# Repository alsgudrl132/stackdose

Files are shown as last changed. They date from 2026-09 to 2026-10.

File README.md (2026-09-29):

# stackdose

**버튼 한 번으로 내 보충제 조합(스택) 1회분을 컵에 담아 주는 디스펜서**

가루 4종과 알약·캡슐 4종을 넣어 두고, 웹에서 "운동 전", "운동 후" 같은 프리셋을 누르면 정해 둔 양만큼 담아 줍니다. 컵은 두 개로, 가루 컵은 가루 스테이션 저울 위에, 알약 컵은 알약 스테이션에 놓습니다. 가루는 저울로 무게를 재면서 목표량이 되면 멈추고, 알약은 원판이 돌면서 한 알씩 떨어뜨립니다.

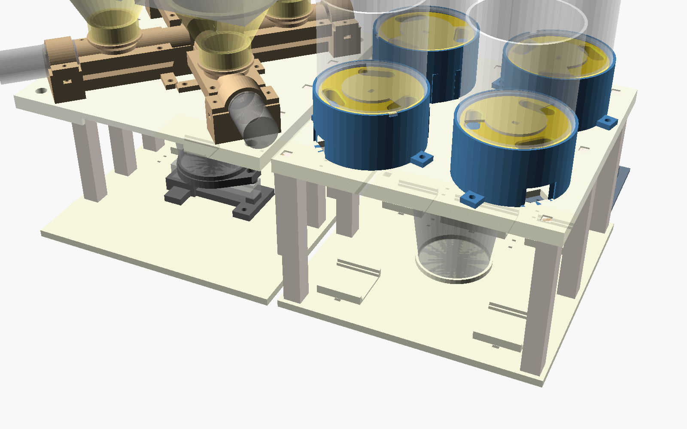
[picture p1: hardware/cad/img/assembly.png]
전체 조립


> **진행 상황 (2026-09):** 3D 설계와 배선 설계를 마쳤고, 부품을 주문하는 단계입니다. 아직 실물로 만들어 보지 않았습니다. 다음은 웹(백엔드 + 가상 디스펜서)입니다.

## 기능

- **프리셋 3개 이상:** 사용자 설정 1·2·3…마다 가루 몇 g, 알약 몇 알을 저장
- **가루 4칸:** 스크류(오거)가 가루를 밀어내고, 컵 밑 로드셀로 무게를 보면서 목표 g에서 멈춤 (폐루프)
- **알약 4칸:** 칸이 3개인 원판이 120°씩 돌아 한 알씩 배출. 자석 + 홀 센서로 원점을 찾음
- **웹 먼저:** 하드웨어가 없어도 가상 디스펜서로 전체 흐름을 돌려 볼 수 있게 만들 예정

## 구조

| 가루 모듈 | 알약 모듈 |
|---|---|
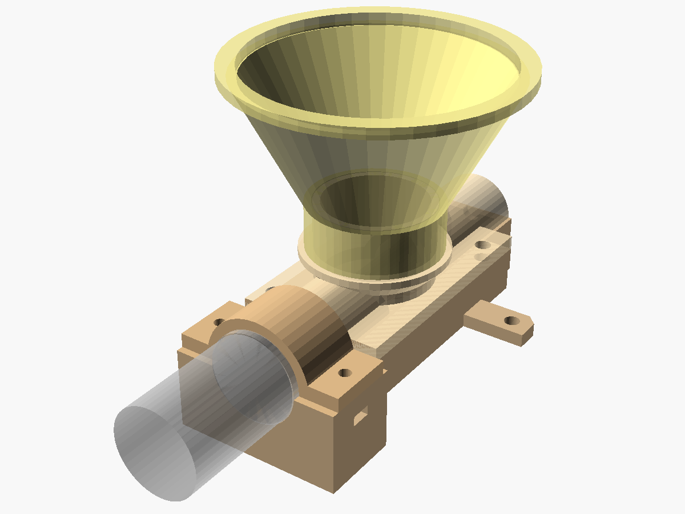
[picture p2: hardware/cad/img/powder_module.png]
가루 모듈
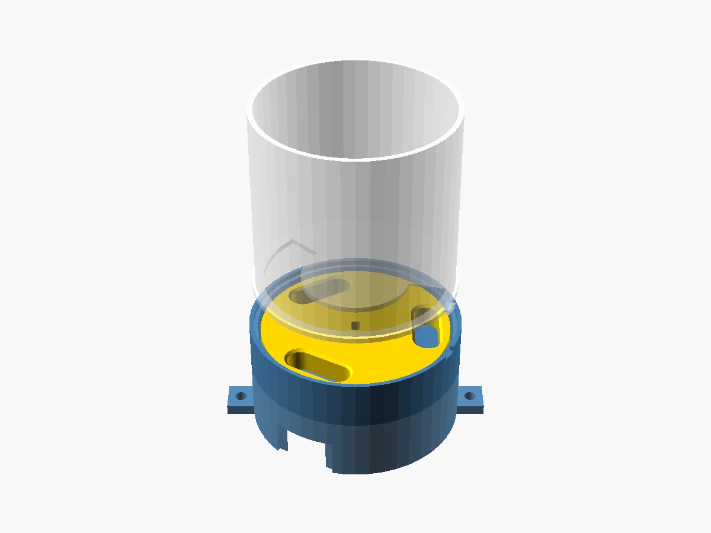
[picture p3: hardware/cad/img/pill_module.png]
알약 모듈
|  |  |
| JGA25-370 DC 모터 + 3D 프린트 스크류. 네 모듈이 컵 위에서 X자로 모임 | 28BYJ-48 스텝 모터 + 칸 3개 원판. 출구 아래 미끄럼관이 컵으로 이어짐 |

```
웹 (프리셋 선택) ──HTTP──▶ ESP32 ─┬─ DRV8833 ×2 ── 가루 모터 ×4
                                 ├─ MCP23017 (I2C) ── ULN2003 ×4 ── 알약 모터 ×4
                                 ├─ HX711 ── 로드셀 1kg (컵 무게)
                                 └─ 홀 센서 ×4 (알약 원판 원점)
```

## 폴더

| 폴더 | 내용 |
|---|---|
| [hardware/cad](hardware/cad) | OpenSCAD 설계 (치수는 `config.scad` 한 곳), 출력용 STL, 자동 검사 스크립트 |
| [hardware/wiring.md](hardware/wiring.md) | 전원, ESP32 핀 배정, 선 길이 |
| [hardware/parts.md](hardware/parts.md) | 부품표 |
| `backend/` · `frontend/` · `firmware/` | 예정 |

## 설계 원칙

- **서포트 없이 출력:** 모든 부품이 Ender-3 SE(220×220mm)에 서포트 없이 들어가도록 방향과 모양을 잡았습니다.
- **나사 20개:** 힘을 받는 곳(모터, 로드셀)에만 나사를 쓰고, 나머지는 핀·돌기·턱으로 끼우거나 한 덩어리로 출력합니다.
- **검사하고 출력:** `python hardware/cad/check.py`가 부품 렌더 오류, 출력판 크기, 떨어진 조각, 조립 상태의 부품 겹침(155쌍), 컵을 꺼내는 길, 알약 원판의 대기 위치를 검사합니다. `overhang.py`는 서포트가 필요한 면을 찾습니다.
- **공차는 쿠폰으로:** 프린터마다 다른 끼워 맞춤 여유를 공차 쿠폰 하나로 재서 `config.scad`에 넣습니다.

## 로드맵

- [x] 3D 설계 · 자동 검사
- [x] 배선 설계 · 부품 선정
- [ ] 백엔드: FastAPI + SQLite (프리셋, 배출 기록)
- [ ] 프론트엔드: 프리셋 화면 + 가상 디스펜서
- [ ] 펌웨어: ESP32 (무게 폐루프 배출, 원점 찾기)
- [ ] 출력 · 조립 · 실측값 반영

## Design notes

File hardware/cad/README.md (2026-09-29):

# stackdose · 3D 설계 (8칸: 가루 4 + 알약 4)

모든 치수는 [config.scad](config.scad) 한 곳에 있습니다. ★가 붙은 값은 **추정치**라, 부품이 도착하면 아래 측정표대로 재서 고칩니다. 숫자를 고친 뒤에는 `python check.py`로 다시 검사합니다.

OpenSCAD에서는 **파일 → 열기**로 `assembly.scad`를 여세요. 코드를 복사해서 새 창에 붙이면 `include` 파일을 못 찾습니다.

## 구조

- **가루 스테이션 (왼쪽, 210×210mm):** 스크류 4개가 컵을 중심으로 X자로 모이고, 출구 4개가 컵 입구 안으로 바로 떨어집니다. 모터는 JGA25-370이고, 반원 받침과 덮개 띠로 감싸 약 0.3mm 눌러 잡습니다. 가루통은 깔때기(호퍼) 위에 얹습니다. 컵은 로드셀 저울 위에 있어서, 무게를 보면서 스크류를 돌리고 목표량이 되면 멈춥니다.
- **알약 스테이션 (오른쪽, 205×205mm):** 원판 모듈 4개가 2×2로 놓입니다. 원판에는 칸이 3개라서 120° 돌 때마다 한 알이 나갑니다. 원판 밑의 자석과 바닥의 홀 센서로 원점을 찾습니다. 각 출구에서 비스듬한 미끄럼관을 타고 컵까지 내려갑니다.
- **제어판 (알약 스테이션 뒤):** 만능기판, ESP32, DC 잭. 배선은 [../wiring.md](../wiring.md)에 있습니다.
- 두 스테이션과 제어판은 따로 서 있고, 전선만 오갑니다. 컵은 두 스테이션 모두 **4.5mm 들어 올려 앞으로** 뺍니다.

## 파일

| 파일 | 부품 |
|---|---|
| `coupon.scad` | 공차 쿠폰 (가장 먼저 출력) |
| `powder.scad` | 가루 모듈: 아래 반쪽 관 + 모터 받침, 위 반쪽 관 + 칼라, 모터 덮개 띠, 호퍼, 스크류 |
| `pill.scad` | 알약 모듈: 치마, 바닥, 원판, 덮개 + 호퍼 (미끄럼관 모양은 여기, 출력은 알약 상판에 붙어서) |
| `scale.scad` | 저울: 로드셀 받침(과부하 멈춤대 포함), 컵 쟁반, 간격 와셔 |
| `frame.scad` | 스테이션별 바닥판(보드 받침 포함)·상판(알약 쪽은 미끄럼관 포함), 기둥, 핀 |
| `electronics.scad` | 제어판(만능기판·ESP32·DC 잭 받침 한 판), 바닥판에 붙는 보드 받침 모양 |
| `layout.scad` | 모듈 배치 계산 |
| `assembly.scad` | 전체 조립 미리보기 |
| `check.py` · `overhang.py` | 자동 검사 (아래) |

## 자동 검사가 보는 것

`python check.py` 하나로 전부 돌아갑니다.

| 검사 | 내용 |
|---|---|
| parts | 부품마다 렌더 오류 없음, 출력판(220×220×250) 안, **한 덩어리** (떨어진 조각 없음) |
| rest | 알약 원판이 멈춰 있을 때 칸이 출구 위에 걸치지 않음 |
| clash | 조립 상태에서 부품끼리 겹침 없음 (155쌍). 컵 꺼내는 길, 호퍼·가루통, 홀 센서 포함. 모터 덮개 띠의 조임만 의도한 겹침으로 허용 |
| overhang | `python overhang.py` — 서포트 없이 뽑을 수 없는 면이 있는지 |

## 출력 순서

큰 판은 작은 부품이 전부 맞는 걸 확인한 **맨 마지막**에 뽑습니다. 모듈은 **1벌 먼저** 뽑아 돌려 보고, 맞으면 나머지 3벌을 뽑습니다.

| 순서 | 부품 | 개수 | 확인할 것 |
|---|---|---|---|
| 1 | coupon | 1 | 아래 "쿠폰 읽는 법" → config 값 고치고 `check.py` |
| 2 | auger · powder_top · powder_block · powder_strap · powder_hopper | 1씩 | 스크류가 관 안에서 부드럽게 도는지, 모터가 받침에 꽉 물리는지 |
| 3 | pill_disk · pill_skirt · pill_floor · pill_cover | 1씩 | 원판이 도는지, 캡슐이 칸에 눕는지, 자석이 홀 센서 위에서 읽히는지 |
| 4 | scale_pedestal · scale_tray · scale_spacer | 1·1·2 | 로드셀 볼트가 맞는지 |
| 5 | pins | 1판 | 핀이 모듈·상판 구멍에 헐겁지 않게 들어가는지 |
| 6 | 2번 · 3번의 나머지 | 3벌씩 | |
| 7 | ctrl_plate | 1 | ESP32·만능기판이 들어가는지 |
| 8 | post | 14 | 가루 7 + 알약 7. 눕혀서 출력 |
| 9 | base_powder · deck_powder · base_pill · deck_pill | 1씩 | 가장 오래 걸림. 바닥판에 보드 받침, 알약 상판에 미끄럼관이 붙어 있음 |

출력 설정(PLA, Ender-3 SE): 레이어 0.2mm, 벽 3줄, 채움 25%, **서포트 없음**. STL은 출력 방향으로 들어 있습니다.

## 쿠폰 읽는 법

| 줄 | 표시 | 고를 칸 | 바꿀 값 |
|---|---|---|---|
| 1 | C | 8mm 핀이 **돌지만 흔들리지 않는** 칸 | `clear` = 0.1 × 칸 번호 |
| 2 | J | JGA25-370 축이 **손으로 꽉 끼는** 칸 | 스크류 허브 여유 (알려 주세요) |
| 3 | B | 28BYJ-48 축이 **손으로 꽉 끼는** 칸 | 원판 허브 여유 (알려 주세요) |
| 4 | M | M3 나사가 **힘 없이 지나가는 가장 작은** 칸 | `m3_hole` = 3.1 + 0.1 × 칸 번호 |
| 5 | H | M3 너트가 **눌러야 들어가고 안 빠지는** 칸 | `m3_nut_af` = 5.5 + 0.1 × 칸 번호 |

C 줄의 값(`clear`)이 핀·기둥 돌기·치마 턱의 헐거움을 모두 정합니다.

## 측정표 (부품 도착 후)

| 부품 | 잴 것 | config 이름 | 지금 값 |
|---|---|---|---|
| 28BYJ-48 | 몸통 지름 · 높이 | `byj_body_d` · `byj_body_h` | 28 · 19 |
| | 고정 구멍 중심 간격 · 귀 두께 | `byj_ear_span` · `byj_ear_t` | 35 · 0.8 |
| | 몸통 중심 ↔ 축 중심 거리 | `byj_shaft_off` | 8 |
| | 축 지름 · 깎인 폭 · 돌기 위 길이 · **깎인 부분 길이** | `byj_shaft_d` · `byj_shaft_flat` · `byj_shaft_len` · `byj_flat_len` | 5 · 3 · 9 · 6 |
| | 전선 길이 · 커넥터 크기 | (알려 주세요) | 25cm · 12.5×6 |
| JGA25-370 | 치수도 값을 넣어 둠. 실제와 다르면 | `jga_*` | 치수도 |
| 로드셀 | 치수도 값을 넣어 둠 | `lc_*` | 치수도 |
| 컵 (다이소) | 바닥 지름 · 입구 지름 · 높이 | `cup_*` | 55 · 75 · 75 |
| 가루통 ×4 (다이소) | 바닥 한 변 (85mm 이하) | `bin_w` (assembly) | 85 |
| | 바닥에 뚫을 구멍 | `hop_top_id` (powder) | 70 |
| 캡슐 · 알약 | 길이 · 폭 · 두께 | `pill_l` · `pill_w` · `pill_t` | 23.5 · 8.5 · 8.5 |
| ESP32 | 보드 가로 · 세로 | `esp_w` · `esp_d` | 54.4 · 27.9 |
| ULN2003 · MCP23017 · HX711 | 보드 가로 · 세로 | `uln_*` · `mcp_*` · `hx_*` | 35×33 · 55×32 · 35×21 |
| 홀 센서 (49E) | 알맹이 폭 · 높이 · 두께 | `hall_w` · `hall_l` · `hall_t` | 4.2 · 3.2 · 1.6 |
| DC 잭 | 몸통 지름 | `dcj_d` | 11 |

## 나사 개수 (20개)

나사는 **힘을 받는 곳에만** 씁니다. 나머지는 끼우거나 얹습니다.

| 어디 | 나사 | 너트 |
|---|---|---|
| 가루 모터 덮개 띠 (모터 4개 × 2) | M3x12 × 8 | 8 |
| 알약 모터 (4개 × 2) | **M3x5** × 8 | 8 |
| 로드셀 고정 끝 / 쟁반 끝 | M5x15 × 2 / M4x12 × 2 | (로드셀 나사산에 바로) |

알약 모터 나사는 반드시 **M3x5**여야 합니다. 더 길면 끝이 원판 밑에 닿습니다.

## 나사 없이 붙는 곳

| 어디 | 방법 |
|---|---|
| 기둥 ↔ 바닥판 · 상판 | 기둥 양 끝 네모 돌기를 판의 네모 구멍에 끼움. 상판은 기둥 위에 얹힘 |
| 가루 모듈 ↔ 상판 | 상판 핀 구멍에 핀 2개를 넣고 모듈을 얹음 |
| 가루 모듈 위 관 ↔ 아래 관 | 핀 2개. 위에 호퍼와 가루통이 얹혀서 눌림 |
| 알약 모듈 ↔ 상판 | 핀 2개 |
| 알약 치마 ↔ 바닥 | 치마 윗면 턱에 바닥의 홈이 끼워짐 (돌지 않게 키 1개) |
| 알약 미끄럼관 | 상판과 한 덩어리로 출력 |
| 저울 받침 ↔ 바닥판 | 핀 2개 |
| 보드 (ULN2003 ×4, MCP23017, HX711) | 바닥판에 붙은 받침에 올리고 케이블 타이 하나 |
| ESP32 · 만능기판 · DC 잭 | 제어판 받침에 올림 / 홈에 밀어 넣음 / 케이블 타이 |

핀은 `pins` 한 판에 30개(26개 + 여분 4)가 들어 있습니다.

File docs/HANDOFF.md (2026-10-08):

# stackdose 인수인계 (2026-09-22 기준)

다음 세션(사람이든 Claude든)이 이 문서 하나만 읽고 이어서 일할 수 있게 쓴 문서입니다.
**확인한 것 / 추정(★) / 모르는 것**을 구분해 두었습니다. ★가 붙은 값을 사실처럼 말하지 마세요.

---

## 0. 한 줄 요약

보충제 디스펜서입니다. 가루 4칸은 스크류와 로드셀로 g 단위까지 담고, 알약 4칸은 원판으로 한 알씩 떨어뜨립니다. 웹 프리셋으로 1회분을 담습니다. **컵은 두 개**입니다 (가루 컵은 가루 스테이션 저울 위, 알약 컵은 알약 스테이션).

- **완료:** 3D 설계, 배선 설계, 부품 선정, GitHub 첫 커밋 (`41adc28`)
- **아직 안 함:** 실물 출력과 조립, 부품 실측, 웹, 펌웨어
- **다음 할 일:** 부품이 오면 쿠폰부터 출력. 그동안은 웹 백엔드부터 시작

---

## 1. 지금 상태

| 항목 | 상태 | 비고 |
|---|---|---|
| 3D 설계 (OpenSCAD) | ✅ 완료, 자동 검사 전부 통과 | `hardware/cad/` |
| 배선표 | ✅ | `hardware/wiring.md` |
| 부품표 | ✅ | `hardware/parts.md` |
| 부품 주문 | ⏳ 장바구니 정리까지 함. **결제했는지는 모름** | 아래 7장 |
| 출력 · 조립 | ❌ | 쿠폰부터 |
| 백엔드 (FastAPI + SQLite) | ❌ | 아래 9장 |
| 프론트 (프리셋 화면 + 가상 디스펜서) | ❌ | |
| 펌웨어 (ESP32) | ❌ | |

GitHub에는 첫 커밋 뒤에 한 가지가 더 바뀌어 있고, 아직 커밋되지 않았습니다. `hardware/parts.md`에서 28BYJ 세트를 "구매 3 + 집에 1"로 고친 것입니다.

---

## 2. 폴더

```
stackdose/
├─ README.md               GitHub 첫 화면
├─ CLAUDE.md               Claude Code 세션이 자동으로 읽는 짧은 안내
├─ CLAUDE.local.md         (git 제외) 사용자와 일하는 방식
├─ docs/HANDOFF.md         이 문서
├─ hardware/
│  ├─ parts.md             부품표 (디바이스마트)
│  ├─ wiring.md            전원 · 핀 배정 · 선 길이 · 전류
│  └─ cad/
│     ├─ README.md         출력 순서 · 쿠폰 읽는 법 · 측정표 · 나사 개수
│     ├─ config.scad       ★ 모든 공통 치수 (여기만 고침)
│     ├─ lib.scad          공용 2D/3D 모양 (slot2d, sector2d, D컷 축, teardrop, 너트 주머니 …)
│     ├─ layout.scad       모듈 배치 계산 (powder_xy, pill_center, at_powder, at_pill, at_slide …)
│     ├─ powder.scad       가루 모듈
│     ├─ pill.scad         알약 모듈 (+ 미끄럼관 모양)
│     ├─ scale.scad        저울
│     ├─ frame.scad        바닥판 · 상판 · 기둥 · 핀
│     ├─ electronics.scad  제어판, 바닥판에 붙는 보드 받침
│     ├─ assembly.scad     전체 조립 + piece(name) (겹침 검사용)
│     ├─ coupon.scad       공차 쿠폰
│     ├─ check.py          자동 검사 (parts / rest / clash)
│     ├─ overhang.py       서포트 필요 면 찾기
│     ├─ img/              README용 렌더
│     └─ stl/              출력용 STL (check.py parts 가 다시 만듦)
└─ tools/devicemart/       (git 제외) 디바이스마트 조회 스크립트
```

**예전 위치:** `C:\Users\min\Desktop\dev\sb-study\dispenser\`는 이 저장소로 옮기기 전의 사본이라 이제 안 씁니다. 거기의 `cad/pill_module_v0.scad`는 초기 시안이라 버려도 됩니다.
같은 `sb-study` 안의 `backend/`·`frontend/`는 **중단된 MT5 토이 프로젝트**입니다. stackdose와 관계없고, 다시 실행하면 안 됩니다. 이유는 `CLAUDE.local.md`에 있습니다.

---

## 3. 하드웨어 전체 그림

좌표는 mm이고 X는 왼쪽→오른쪽, Y는 앞→뒤, Z는 위입니다. 원점은 두 스테이션 사이, 바닥판 윗면입니다.

| 덩어리 | 위치 | 크기 |
|---|---|---|
| 가루 스테이션 P | 컵 중심 `cupP = [-110, 0]` | 판 210×210 |
| 알약 스테이션 L | 컵 중심 `cupL = [105, 0]` | 판 205×205 |
| 제어판 | `ctrl_c = [105, 152.5]` (L 뒤, 탁자 위) | 190×90 |

공통 높이:

| 항목 | 값 |
|---|---|
| 바닥판 두께 | `base_t = 6` (z −6~0) |
| 기둥 | 14×14, z 0~120 |
| 상판 | 아랫면 `deck_z = 120`, 두께 `deck_t = 5` → 윗면 `deck_top = 125` |
| 상판 테두리 | 아래로 `rim_h = 6`, 폭 `rim_w = 3` |

두 스테이션과 제어판은 따로 서 있고 전선으로만 이어집니다. 컵은 두 스테이션 모두 **4.5mm 들어 올린 뒤 앞(−Y)으로** 빼며, 그 길은 겹침 검사(`sweepP`, `sweepL`)로 확인합니다. 가루 쪽은 앞에 기둥이 없고, 상판 앞 테두리에 컵 폭+12 홈이 있습니다.

### 3.1 가루 모듈 (`powder.scad`) × 4

- **배치:** 가루 컵 중심에서 X자로 놓입니다 (`powder_a = [45,135,225,315]`). 출구 끝면이 컵 중심에서 `powder_d = 13`에 있습니다. 로컬 +Y가 바깥쪽입니다.
- **네 모듈의 경계:** 각 모듈은 자기 90° 구역 안에만 있도록 `own_sector()`로 잘려 있고, 이웃 모듈과 1.2mm 틈이 있습니다. 원래 앞 날개 모서리가 2.8mm 겹쳐서 이렇게 고쳤습니다.
- **관과 스크류:**
  - **관 안지름 16은 고정**입니다. 스크류 지름 = `16 − 2 × auger_gap` (config, 지금 0.5 → 15.0). 틈을 바꿀 땐 **스크류만** 다시 뽑고 block·top은 그대로 씁니다.
  - 피치 40, 날개 두께 3, 1줄 나선, 코어 6. 스크류 전체 길이는 약 80입니다 (85는 관 길이).
  - 관 길이 `L = 85` (`endcap_t 3.8 + L_in 81.2`), 축 높이 `axis_h = 24` (상판 윗면 기준).
  - 출구 13×12는 컵 쪽 끝 아래에 있습니다.
- **스크류 끝 핀:** `tip_d = 5`, 막힌 구멍 깊이 `tip_hole_d = 2.5`, 구멍 앞 벽 1.3. 막힌 구멍이라 앞으로 가루가 새지 않습니다.
  - ⚠ 이 변수는 원래 이름이 `pin_*`였는데, config의 위치 맞춤 핀과 이름이 겹쳐서 `tip_*`로 바꿨습니다. 13장을 보세요.
- **부품 5개:**
  - `block`: 아래 반쪽 관 + 모터 받침
  - `top`: 위 반쪽 관 + 칼라 Ø33 + 호퍼 턱
  - `strap`: 모터 덮개 띠
  - `hopper`: 칼라에 씌우는 60° 깔때기, 윗구멍 `hop_top_id = 70★`, 테두리 Ø80
  - `auger`: 스크류
- **모터 고정 (JGA25-370):**
  - 받침 윗면을 축보다 1mm 낮췄습니다 (`split_dz = 1.0`).
  - 띠 구멍 중심을 축보다 0.4 낮췄습니다 (`squeeze = 0.4`). 그래서 M3x12 두 개로 조이면 감속기를 약 0.3mm 눌러 잡습니다.
  - 겹침 검사에서 `motor×powder` 76mm³는 이 조임이라 허용합니다 (`ALLOW` 100mm³).
- **스크류 허브:** D컷 구멍 `hub_hole = shaft_len − boss_h − powder_hub_gap + 1.5`. 모터 돌기(boss)에 닿지 않게 `auger_y_end = L − boss_h − powder_hub_gap`(0.5)로 끝냅니다. D구멍 여유는 `jga_d_clear` (★ J줄).
- **나사 없이 조립:**
  - 상판 ↔ block: 앞 날개 핀 2개 (`powder_deck_holes()`, ±25)
  - block ↔ top: 대각선 핀 2개 (`pin_at`)
  - 위에 호퍼와 가루통이 얹혀서 무게로 눌립니다.
- **상판 전선 구멍:** 모터 전선은 대각선 r=128, Ø9 구멍으로 내려갑니다 (모터 몸통 바로 아래).
- **가루통:** 다이소 용기, 바닥 한 변 85 이하 ★. 바닥에 Ø70 구멍을 뚫어 호퍼 테두리 위에 얹습니다.

### 3.2 알약 모듈 (`pill.scad`) × 4

- **배치:** 알약 컵 중심에서 2×2로 놓입니다 (`pill_s = 51`, 모듈 중심이 대각선 72.1). 로컬 +Y(출구 90°)가 컵 쪽입니다.
- **원판:** 칸 3개, 칸 중심 반지름 `pocket_r = 27`. 원판 지름 74.3, 모듈 지름 82.5.
- **알약 크기 (2026-10-04 결정): 몸체는 최대 알약, 원판은 칸에 넣을 알약**
  - 칸 하나 크기로 모든 알약을 받을 수는 없습니다. 큰 알약에 맞추면 작은 알약이 겹치거나 세워져서 두 알씩 들어갑니다.
  - **몸체**(치마·바닥 출구·낙하관·우물 깊이·덮개 창·알약 상판 미끄럼관): 최대 알약 `pill_max_*` = 26×11×11 ★ (오메가3 1000mg 연질캡슐급, 확인 안 된 추정). 한 번만 뽑습니다.
  - **원판 칸·원판 두께**: 칸에 넣을 알약 `pill_*` = 종근당 멀티비타민 실측 18.2×9.2×5.9. 칸은 길이 +1.8, 폭 +1.0, 원판 두께는 +0.8 (= 6.7).
  - **받침판** (`pill_spacer`): 얇은 알약이면 원판을 얇게 뽑고, 우물 바닥에 받침판(최대 두께 − 원판 두께, 지금 5.1)을 깔아 원판 윗면 높이를 맞춥니다. 덮개 틈 1.5는 그대로입니다. 키(180°)로 출구 구멍을 바닥과 맞춥니다. 원판 허브는 받침판 구멍을 지나 모터 축까지 내려가서 물림 길이는 그대로입니다.
  - **알약을 바꾸면** `pill_*`만 바꾸고 원판·받침판만 다시 뽑습니다. 칸마다 알약이 달라도 됩니다.
  - **한 칸에 한 알 검사:** 원판이 두꺼워 두 알이 겹쳐 들어가거나, 세운 두 알이 나란히 들어가면 렌더가 실패합니다 (`pill.scad` assert).
  - 자석 ↔ 홀 센서 거리는 받침판만큼 멀어집니다 (지금 약 7mm). 8×3 자석이면 이 거리에서도 49E 출력이 0.6V 넘게 움직여서 원점 찾기에 충분하다고 계산했습니다 (추정, 실물 확인 필요).
  - 칸 윗면을 1mm 모따기했습니다.
- **대기 위치:** 칸이 30°·150°·270°에 있고 출구는 90°입니다. 칸 끝이 출구에서 6° 이상 떨어져 있습니다 (`rest` 검사).
  - 한 알 = 120° 회전입니다.
  - 원래 칸이 4개였는데, 4개면 어떤 각도에 세워도 칸이 출구에 걸쳐서 3개로 바꿨습니다.
- **덮개 창:** 출구 ±75°는 닫혀 있고, 나머지 구간으로 호퍼 속 알약이 칸에 들어갑니다. 창이 끝나는 쪽 모서리는 아래를 45°로 깎아서, 반쯤 걸친 알약을 끼우지 않고 밀어 넣습니다.
- **틈:** 원판 아래 0.5, 위 1.5.
- **축 구멍:** 28BYJ 축은 끝의 6mm★(`byj_flat_len`)만 D컷이라, 원판 구멍도 아래는 둥글게, 위쪽만 D자로 만들었습니다.
- **부품과 출력 방향:**
  - `skirt`: 모터가 들어가는 치마 + 낙하관 + 상판 핀 날개 2개 (30°, 210°) + 윗면 턱
  - `floor`: 바닥 + 원판 우물 + 덮개 턱
  - `disk`: 원판. 뒤집어서 출력
  - `cover`: 덮개 + 호퍼 70mm★
- **치마 ↔ 바닥:** 나사 없이 치마 윗면 안쪽 턱(1.2×2)에 바닥 아랫면 홈이 끼워집니다. 150°에 돌림 방지 키가 있습니다.
- **모터 (28BYJ-48):**
  - 귀 두 개를 아래에서 M3x5로 바닥에 조입니다.
  - 너트는 바닥 윗면(우물 쪽) 주머니에 들어가고, 주머니는 0.8 더 깊게 팠습니다.
  - ⚠ **M3x5보다 긴 나사를 쓰면 끝이 원판 밑에 닿습니다.**
- **원점 (홀 센서):**
  - 원판 아랫면 칸 사이에 자석 8×3 (r27.5, 대기 상태에서 350°)
  - 바로 아래 바닥 밑에 홈을 파서 바닥을 1.2mm만 남기고, 49E 센서 알맹이를 넣습니다.
  - 센서 다리와 단선은 바깥쪽 홈(7×1.8)을 따라 치마 벽으로 갑니다.
  - 자석과 센서 사이는 약 1.7mm입니다.
  - 센서는 KY-035 보드에서 떼어 다리에 단선을 납땜하고 수축튜브를 씌웁니다.
  - 센서를 홈에 고정하는 방법은 정하지 않았습니다. 테이프나 글루건 정도면 됩니다 ★.
- **전선 창:** 치마 −Y쪽에 24×14. 상판 전선 구멍(20×12)은 모듈 로컬 (0, −30)에 있습니다. 28BYJ 커넥터(약 12.5×6★)가 꽂힌 채로 통과합니다.
- **미끄럼관:** 출구에서 컵까지 이어지고, **알약 상판과 한 덩어리**로 출력합니다 (`pill_slide_solid/hole`).
  - 위: r = 45.1, z = 120
  - 아래: r = 22, z = 87 (컵을 들어 빼도 닿지 않는 높이)

### 3.3 저울 (`scale.scad`)

- **로드셀:** 1kg 바 타입 (80×12.7×12.7, 치수도). X 방향으로 가루 컵 아래에 눕힙니다.
- **고정 끝 (전선 나오는 쪽):** M5x15 두 개를 받침 아래에서 올려 끼웁니다. 머리는 5.2 파묻히고, 나사가 로드셀에 8.2mm 물립니다.
- **쟁반 끝:** M4x12 두 개를 쟁반 위에서 내려 끼우고, 사이에 간격 와셔 3mm를 넣습니다. 쟁반 두께는 7, 머리는 4.2 파묻히고, 6.2mm 물립니다.
- **assert:** 물림 길이가 5 이상이고 로드셀 두께보다 짧은지 파일 안에서 확인합니다.
- **받침:** 멈춤대까지 한 덩어리 띠(두께 6)입니다. 로드셀 끝 아래에 1.0mm 틈을 둔 과부하 멈춤대가 있습니다. 바닥판에는 핀 2개로 놓습니다.
- **컵 높이:** 컵 바닥은 z 34.7, 컵 윗면은 109.7 ★(컵 높이 75 기준).

### 3.4 뼈대 (`frame.scad`)

- **기둥:**
  - P 7개 `postsP` (컵 기준 ±93, 앞쪽 없음), L 7개 `postsL` (±92)
  - 양 끝에 6×6×4 네모 돌기가 있고, 판의 네모 관통 구멍에 끼웁니다.
  - 돌기는 기둥 한쪽 면에 붙어 있습니다 (`peg_off = -4`). 눕혀서 출력할 때 바닥에 닿게 하려는 것입니다.
  - L 기둥은 원래 ±93~95였는데 상판 테두리를 파고들어서 ±92로 옮겼습니다.
- **상판:** 뒤집어서 출력합니다. 모듈 핀 구멍은 윗면에서 3mm 막힌 구멍입니다.
- **바닥판:** 보드 받침이 붙어 있고, 케이블 타이 구멍과 바닥판 아랫면 타이 홈이 있습니다. 알약 바닥판에는 알약 컵 받침 링(높이 4)이 있습니다.
- **핀:** `pins` 한 판에 30개 (필요 26 + 여분 4). Ø4×6.5, 구멍은 `pin_hole = 4 + 2*clear`.

### 3.5 전자부품 받침 (`electronics.scad`)

- **제어판 (190×90×3, 한 판으로 출력):**
  - 만능기판 89×52 홈 받침: −X에서 밀어 넣고 +X 끝에서 멈춥니다. 긴 변 2mm 턱이 기판 윗면을 덮으니, 그 2mm 안에는 부품을 두면 안 됩니다.
  - ESP32 받침: 세로로 놓고 짧은 두 끝만 받칩니다 (높이 30). USB는 뒤쪽(+Y)입니다. **점퍼를 먼저 다 꽂고 올려놓는 방식**입니다.
  - DC 잭 받침: 케이블 타이로 고정합니다.
- **바닥판에 붙은 보드 받침** (가장자리 턱 1.5, 보드 아랫면 높이 4, 짧은 두 변은 열림, 케이블 타이 하나):
  - ULN2003 ×4: 알약 컵 기준 (±62, ±62). 각 알약 모듈 전선 구멍 바로 아래입니다.
  - MCP23017: (0, 62)
  - HX711: 가루 컵 기준 (−55, 55)

---

## 4. 전자 · 배선 요약 (자세한 건 `hardware/wiring.md`)

- **전원:** 5V 4A 어댑터 하나. 코드에서 **한 번에 모터 하나만** 돌립니다 (최악 약 1.9A).
- **ESP32 핀:**

| 용도 | 핀 |
|---|---|
| I2C (MCP23017) | 21 SDA / 22 SCL |
| HX711 | 18 DT / 33 SCK |
| DRV8833 #1 | 25, 26 (가루1) · 27, 13 (가루2) |
| DRV8833 #2 | 32, 23 (가루3) · 4, 19 (가루4) |
| nFAULT (두 드라이버 묶음) | 5 (10kΩ 풀업. 부팅 때 HIGH여야 하는 핀이라 풀업과 맞음) |
| 홀 센서 1~4 (아날로그, ADC1이라 와이파이를 켜도 읽힘) | 36, 39, 34, 35 |

- **쓰지 않은 핀:** 0, 2, 12, 15 (부팅), 6~11 (메모리 칩), 1, 3 (USB), 16, 17 (WROVER 모듈이면 못 씀).
- **MCP23017:** 주소 0x20. GPA0~3 → ULN #1, GPA4~7 → #2, GPB0~3 → #3, GPB4~7 → #4. RESET은 3V3에 이어야 합니다 (보드에 이미 연결돼 있는지는 ★).
- **DRV8833 (VLT-MD012):** EEP(nSLEEP)를 **3V3에 꼭 이어야** 모터가 돕니다. 모터 전원(VM)은 5V입니다. 모터 하나에 두 핀을 쓰고 둘 다 PWM이 됩니다.
- **부품 추가:**
  - 1000µF를 DRV마다 1개, DC 잭 옆에 1개
  - 0.1µF를 가루 모터 단자마다 1개
  - I2C 풀업 4.7kΩ ×2
- **선:**
  - 단선 0.6: 1개를 사면 빨강·검정·흰색이 1m씩 옵니다. 필요량은 빨강·검정 약 4.9m, 흰색 약 3.2m이라 6개를 삽니다.
  - F-F 30cm: ESP32, MCP, ULN에 씁니다.
  - 구간별 길이는 wiring.md에 20% 여유를 넣어 적었습니다.
- **홀 센서를 바꾼 이유:** 처음 고른 A3144E 모듈(VLT-ML005)은 칩 정격이 4.5V 이상이라 3.3V에서는 규격 밖입니다. 5V로 주면 출력도 5V라 ESP32 입력을 망가뜨릴 수 있습니다. 그래서 KY-035(49E 아날로그, 3.3~5V)로 바꿨습니다.

---

## 5. 자동 검사 (`hardware/cad/check.py`)

```
cd hardware/cad
python check.py            # parts + rest + clash 전부 (약 10분)
python check.py parts      # 렌더 오류 · 출력판 크기 · 한 덩어리 여부 → stl/ 다시 만듦
python check.py rest       # 알약 대기 위치에서 칸 ↔ 출구 겹침
python check.py clash powder0 deckL   # 이름이 들어간 쌍만
python overhang.py         # 서포트 필요 면 (44°)
```

- **환경:**
  - OpenSCAD 2021.01 경로: `C:\Program Files\OpenSCAD\openscad.exe`
  - Windows 콘솔에서 한글이 깨지면 `PYTHONIOENCODING=utf-8`을 붙입니다.
- **판정 방식:**
  - clash는 `assembly.scad`의 `piece(name)` 두 개를 교집합해 부피 1mm³ 이상이면 실패입니다. 15개씩 동시에 돌립니다.
  - "한 덩어리"는 OpenSCAD 로그의 `Volumes: 2`(바깥 + 덩어리 1개)로 판정합니다. `coupon`과 `pins`는 원래 여러 조각이라 뺍니다.
  - 경고(떨어진 덩어리 등)가 나와도 실패로 봅니다.
- **마지막 결과:** 아래 "검수 반영" 참고
- **overhang.py의 허점:** 폭 8mm 미만이면 모두 "다리(양쪽이 받쳐진 천장)"로 봅니다. 한쪽만 붙은 "처마"도 놓칩니다. 실제로 놓친 곳: 저울 받침 M5 머리 자리 천장(깊이를 5.8로 늘려 대응), 제어판 기판 홈 위 2mm 턱(줄칼로 다듬기).
- **check.py가 서로 검사하지 않는 쌍:** 한 덩어리로 묶인 block·top·strap, 치마·바닥, 받침·쟁반·와셔. 2026-09-28 검수에서 13쌍을 따로 돌려 모두 비어 있었습니다.
- **검사가 못 보는 것:**
  - 전선 자체의 부피
  - 나사 머리·너트 모형 (나사가 20개로 줄어서 해당하는 곳이 적음)
  - 가루 흐름, 알약 걸림, 홀 센서 신호 세기
  - 휨 (상판이 가루통 무게로 휘는지)
  - 프린터 공차

### 5.1 검수 반영 (2026-09-28)

다른 세션이 설계 전체를 검수했고(설계 오류는 없음), 아래를 반영했습니다.
- 스크류 끝 핀 구멍 앞 벽 0.5 → 1.3 (`endcap_t 3.8`, `L_in 81.2`, L은 85 그대로)
- 저울 받침 M5 머리 자리 깊이 5.2 → 5.8 (천장 처짐 대비. 물림 8.8, 로드셀 두께 12.7 미만)
- 알약 파일 `rim_h/rim_w` → `pill_rim_*` (config의 상판 테두리 값을 소리 없이 덮어쓰고 있었음)
- D구멍 여유를 `byj_d_clear`, `jga_d_clear`로 분리 (전엔 `clear/2`로 우연히 맞음)
- 숫자로 적힌 곳을 변수로: `powder_shoulder_t`(호퍼 턱 2, 4곳), `powder_hub_gap`(0.5), `powder_bolt_len`(12), `powder_nut_drop`(8), `pill_mag_fit`(자석 자리 0.3)
- `check.py`: 허용 겹침 250 → 100, 경고도 실패로 처리

**남은 검수 항목 (실물이 와야 함):**
- (반영됨 2026-10-04) 알약 크기: 몸체는 최대 알약(26×11×11 ★), 원판·받침판은 칸에 넣을 알약 (3.2절 참고). 실제 오메가3를 재면 `pill_max_*`만 확인
- 원판이 축에 마찰로만 붙음: 28BYJ 돌기 높이를 재서 `hub_down` 조정 (허브가 원판보다 먼저 돌기에 얹히게)
- 자석 자리 8.3이 빡빡할 수 있음: 자석이 오면 쿠폰 C줄 1번(8.2)·2번(8.4)에 넣어 보고 `pill_mag_fit` 조정
- 알약 덮개 가운데 Ø40이 평평해서 캡슐이 머물 수 있음: 알약 부품 뽑기 전에 가운데 원뿔 추가
- 로드셀 멈춤대 틈 1.0: 조립 후 1kg 올려 휘는 양 재고, 테이프로 맞춤
- 제어판 기판 턱: 뽑은 뒤 줄칼로 다듬기
- (확인됨 2026-10-04) 기둥 돌기 ↔ 판 구멍: `pegtest.stl`(판과 같은 `peg_holes()`)에 뽑은 기둥을 끼워 보니 잘 들어감 → 기둥 나머지 13개 진행

---

## 6. 출력 · 조립 순서

출력 설정은 PLA, 레이어 0.2, 벽 3줄, 채움 25%, **서포트 없음**입니다. STL은 출력 방향으로 들어 있습니다.
- 사용자 슬라이서 프리셋은 서포트 켜짐·벽 2줄이라 **서포트를 끄고 벽 3줄로** 바꿔야 합니다. `xy_hole/contour/elephant_foot` 보정은 0으로 두세요 (쿠폰 값이 무의미해짐).
- **스크류:** 챙(brim) 5mm, 최소 레이어 시간 10초(또는 2개를 같이), 팬 100%. 비틀림은 층 사이가 받으니 코어 Ø6과 허브 계단이 가장 약합니다.
- **큰 판(210):** 챙을 끄세요. 210 + 8×2 = 226이라 220 판을 넘습니다.
- 쿠폰과 실제 부품은 **같은 필라멘트 프리셋**으로 뽑습니다.

1. **coupon:** 결과를 config에 넣고 `check.py`를 다시 돌립니다.
   - 확정: C줄 3번 → `clear = 0.3`, B줄 4번 → `byj_d_clear = 0.15`
   - 미확인: M·H줄(M3 나사·너트 필요), J줄(JGA 모터 필요)
   - G줄(스크류 틈)은 **선택 사항**입니다. 기본값 `auger_gap = 0.5`를 유지합니다 (2026-09-30 결정).
     - 사용자 프린터는 보급형이라, 고리는 설계 16.0 → 실측 약 15.4로 작게 나오고 스크류는 그 안에서 헐렁하게 돕니다. 헐렁한 건 정상이고, 빡빡한 것(가루가 끼어 멈춤)이 더 나쁩니다.
     - 멈춘 뒤 새는 가루는 저울 폐루프(목표 근처 감속, 일찍 멈춤)와 역회전으로 잡습니다.
     - 실제 가루로 돌려서 새는 양이 문제일 때만: 먼저 출구 고무 조각·역회전 늘리기 → 그래도 안 되면 `auger_gap`을 줄이고 스크류만 재출력 (0.3 밑으로는 안 내림).
2. **가루 모듈 1벌** (auger, top, block, strap, hopper): 스크류가 부드럽게 도는지, 모터가 꽉 물리는지 봅니다.
   - **스크류는 1개만 먼저** 뽑아 실제 관과 모터로 확인한 뒤 나머지 3개를 뽑습니다.
3. **알약 모듈 1벌** (disk, skirt, floor, cover): 원판이 도는지, 캡슐이 칸에 눕는지, 자석이 읽히는지 봅니다.
4. **저울** (pedestal, tray, spacer ×2)
5. **pins**
6. **2·3번의 나머지 3벌씩**
7. **ctrl_plate**
8. **post ×14:** 눕혀서 출력합니다.
9. **큰 판 4장** (base_powder, deck_powder, base_pill, deck_pill): 가장 오래 걸립니다.

**조립할 때 주의:**
- **스크류는 먼저 모터 축에 끼우고, 모터와 함께 받침에 내려놓습니다.** 끝 핀 구멍 앞뒤 여유가 0.5뿐이고 축이 허브에 8.5mm 들어가서, 모터를 먼저 놓으면 스크류를 끼울 수 없습니다.
- ESP32는 점퍼를 먼저 꽂고 받침에 올립니다.
- 알약 모터는 바닥에 먼저 조인 뒤 치마 위에 얹습니다.
- 홀 센서 선은 모터 전선과 같이 상판 전선 구멍으로 내립니다.

---

## 7. 부품 · 장바구니

전체 목록은 `hardware/parts.md`에 있습니다. 구매처는 **디바이스마트만** 씁니다. Claude가 직접 확인할 수 있는 곳이 여기뿐이기 때문이고, 방법은 12장에 있습니다.

**원래 장바구니 (114,356원, 부가세 포함):**

| 상품 | 수량 |
|---|---|
| JGA25-370 77RPM | 4 |
| DRV8833 VLT-MD012 | 3 |
| MCP23017 226702 | 1 |
| 28BYJ+ULN2003 세트 SZH-EKBL-007 | 3 (+ 사용자 집 아두이노 세트에 1 → 총 4) |
| HX711 SZH-SSBH-016 | 1 |
| 로드셀 1kg VLT-LCS002 | 1 |
| 아답터 5V 4A | 1 |
| DC 커넥터 SZH-LC002 | 1 |
| 만능기판 89×52 | 1 |
| 핀헤더소켓 1×40 | 2 |
| 2핀 터미널 5.08 | 10 |
| 100µF 25V | 10 |
| 단선 0.6 | 1 |
| 렌치볼트 + 너트 키트 340pcs NT-KIT-LS027 | 1 |

사용자가 따로 F-F 점퍼 30cm를 담았습니다.

**추가하라고 안내한 것 (약 13,480원, 부가세 별도):**

| 상품 | 번호 | 수량 |
|---|---|---|
| KY-035 | no=15959593 | 4 |
| 자석 8×3 | no=15565 | 10 (최소 구매) |
| M3x5 | no=10915191 | 10 |
| M5x15 | no=10912468 | 10 |
| M4x12 | no=10912479 | 10 |
| 1000µF 10V | no=2757 | 10 |
| 0.1µF | no=1399 | 10 |
| 4.7kΩ | no=864 | 30 |
| 10kΩ 1% | no=2034 | 10 |
| 단선 | no=1153807 | 6 (총 개수) |
| 수축튜브 1.5 | no=12782 | 1 |

A3144E 홀 센서(VLT-ML005)를 담았다면 빼라고 했습니다.

**모르는 것:**
- 사용자가 실제로 추가하고 결제했는지
- (확인됨) 키트에 M3×5~20 각 20개, 너트 160개 → 필요한 너트 16개, M3x5 모두 충분 (디바이스마트 no=1385067 상세)

**집에 있는 것:** ESP32-DevKitC V4, 아두이노 세트(28BYJ+ULN2003 1개, 점퍼, 브레드보드), 디지털 캘리퍼, Ender-3 SE, PLA.

---

## 8. 실물이 와야 확정되는 것 (★)

| 항목 | config 값 | 틀리면 생기는 일 |
|---|---|---|
| ~~28BYJ 치수~~ ✅ 2026-10-04 확정 | `byj_*` | 제조사 도면(components101) + 실측. 높이 19.4, 축 길이(돌기 위) 8.5, 귀 간격 35, 파란 덮개(중심에서 17, 폭 14.6)를 검사 모형에 추가 |
| 28BYJ 전선 길이 · 커넥터 크기 | (wiring) | ULN까지 선이 모자람 |
| 컵 지름 · 높이 | `cup_*` | 가루 출구가 컵 밖으로 떨어짐, 컵이 안 빠짐 |
| 가루통 바닥 크기 | `bin_w`(assembly.scad), `hop_top_id`(powder.scad) | 호퍼에 안 얹힘 |
| 최대 알약 크기 | `pill_max_*` (26×11×11 ★) | 더 큰 알약이 몸체를 못 지나감 (몸체 재출력) |
| 칸에 넣을 알약 | `pill_*` (멀티비타민 실측) | 원판·받침판만 다시 뽑으면 됨 |
| 보드 치수 (ULN, MCP, HX, ESP32) | `*_w`, `*_d` | 받침에 안 들어감 → 받침이 바닥판에 붙어 있어서 **바닥판을 다시 뽑아야 함** |
| 49E 센서 알맹이 크기 | `hall_*` | 홈에 안 들어감 |
| 프린터 공차 | `clear`, `m3_*` | 핀이 헐겁거나 빡빡함 |

⚠ 보드 받침이 바닥판과 한 덩어리라서, **큰 판을 뽑기 전에 보드를 실제로 재서 config를 확정해야 합니다.** 출력 순서에서 큰 판이 마지막인 이유입니다.

**동작을 시험해 봐야 아는 것:**
- 가루가 스크류로 고르게 나오는지 (피치 40, 틈 0.5)
- 캡슐이 창 모서리에서 끼지 않는지
- 49E가 자석을 충분히 세게 읽는지 (기준 약 1.65V에서 얼마나 움직이는지)
- 스크류가 막혔을 때 핀만으로 모듈이 들리지 않는지. 막히면 무게가 안 늘어나는 걸 보고 멈추게 할 계획입니다.

---

## 9. 다음 단계: 웹 (사용자가 직접 코딩)

**합의한 방향:** 웹을 먼저 만듭니다. FastAPI + SQLite + 웹 화면으로 실제 서비스처럼 만들고, 기계는 처음엔 같은 명령 형식을 쓰는 "가상 디스펜서" 프로그램으로 대신합니다. 나중에 ESP32로 바꿉니다.

**데이터 초안:**

| 테이블 | 컬럼 |
|---|---|
| `slots` | no, supplement, kind (powder / pill), remaining |
| `presets` | no, name |
| `preset_items` | preset, slot, amount |

컵과 단위는 칸 종류로 정해지니 따로 저장하지 않습니다. 칸 종류는 하드웨어(스크류 / 원판)가 정하므로 기기가 알려 줍니다.

**첫 코드 단계:** 테이블 세 개를 만들고 예시 행을 넣는 것입니다.

**백엔드에서 깊게 다룰 거리:**
- 버튼 두 번 눌림 방지 (idempotency)
- 기기가 꺼져 있을 때 처리와 heartbeat
- 배출 상태 머신
- 재고가 모자랄 때 규칙
- 목표량과 실제 무게 기록

**보류한 아이디어:** 카페인 겹침 경고. 사용자가 보류했으니 먼저 꺼내지 않습니다.

**펌웨어 메모:**
- 가루: PWM으로 돌리면서 HX711 무게를 보고, 목표 근처에서 느리게 → 멈춤. 무게가 안 늘면 막힘으로 보고 잠깐 역회전합니다.
- 알약: 홀 센서로 원점 → 오프셋만큼 돌려 대기 위치 → 한 알마다 120°.
- 쉬는 동안에는 ULN 네 핀을 모두 LOW로 둡니다 (발열 방지).

---

## 10. 결정 기록 (왜 이렇게 했나)

| 결정 | 이유 |
|---|---|
| 2+2 칸 → 4+4 칸 | 사용자: "알약이나 가루 종류 많은데 두개씩밖에…" 프로젝트 가치 |
| 가루는 공용 깔때기 없이 컵 위로 X자 | 가루끼리 섞이지 않게, 쌓이지 않게 |
| 가루는 무게 폐루프 | 스크류 회전 수만으로는 가루마다 양이 다름 |
| 알약 칸 4 → 3 | 칸 4개면 어떤 각도에서도 대기 중 출구와 겹침 |
| A3144E → KY-035 (49E) | 3.3V 규격 · ESP32 입력 보호 |
| 나사 116 → 20개 | 사용자: "이건그냥 토이 프로젝트야… 많아봐야 20개정도" → 힘받는 곳만 나사, 나머지는 핀·돌기·턱·한 덩어리 |
| 미끄럼관을 알약 상판에 붙임 | 상판 아래에 매달 방법이 나사뿐이었음. 상판을 뒤집어 출력하면 관이 위로 서서 서포트가 필요 없음 |
| 보드 받침을 바닥판에 붙임 | 나사를 없애려고. 대신 보드 치수 확정이 먼저 |
| 전자부품을 제어판으로 | 알약 컵을 꺼내는 길이 ESP 받침과 기둥에 막혔음 |
| 로드셀 고정 끝 = 전선 쪽 | 치수도: 전선 끝 M5, 반대 끝 M4 |
| 부품은 디바이스마트만 | 알리·쿠팡은 Claude가 확인할 수 없음 (JS 페이지, 403). 예전에 확인하지 않은 링크를 줬다가 신뢰를 잃음 |
| 준비 기간은 상품별 `shipping_term` | 공통 배송 안내의 "1~3일"을 인용했다가 틀렸음. 2주짜리 상품이 섞여 있었음 |

---

## 11. 설계 파일 수정 규칙

- **숫자는 `config.scad`에서만 고칩니다.** ★ 주석이 있는 값은 실측 후에 바꿉니다.
- 고친 뒤에는 **반드시 `python check.py`**를 돌립니다. 10분이 걸리면 `clash 이름`으로 바뀐 부품만 먼저 봅니다.
- 부품 파일은 서로 `use <…>`로 부르고, `config.scad`·`lib.scad`·`layout.scad`만 `include`합니다.
  - ⚠ `include`한 변수와 부품 파일 안의 변수 이름이 같으면, OpenSCAD는 **파일 안의 마지막 값**으로 덮어씁니다. 경고도 없습니다.
  - 실제로 `pin_d`가 스크류 끝 핀(5)과 위치 맞춤 핀(4)에서 겹쳐 사고가 났습니다. 새 변수는 부품 접두어를 붙이세요.
- 새 부품을 만들면:
  - `check.py`의 `PARTS`에 추가합니다.
  - 조립 위치에 놓이는 것이면 `assembly.scad`의 `piece()`와 `CLASH` 쌍에도 추가합니다.
- 서포트가 없어야 합니다. 아래를 향한 면은 45° 이상이거나 짧은 다리(브리지)여야 합니다. 구멍 천장은 teardrop이나 좁은 폭으로 만듭니다.
- STL은 `check.py parts`가 `stl/`에 다시 만듭니다. 커밋 전에 한 번 돌리세요.

---

## 12. 디바이스마트 조회 (`tools/devicemart/`, git 제외)

사이트가 JS로 그려서 WebFetch로는 빈 껍데기만 옵니다. 그래서 스크립트를 씁니다.

- **검색:** `/goods/search` 페이지에서 `csrf_token`을 받고, `/goods/search_sse_stream?...`의 SSE 이벤트 `sphinx_result` JSON을 읽습니다.
  - `goods_status`: normal / runout / purchasing / unsold
  - `shipping_term`: 준비 기간. 1·2·3·4는 일, 6은 1주, 12는 2주, 18은 3주, 24는 4주
  - `min_purchase_ea`: 최소 구매 수량
  - `sale_price`: 부가세 별도 가격
- **상세 사양:** `/goods/view_contents?no=…`의 HTML입니다. 사양 이미지는 `smarfocus.hgodo.com/.../data/editor/goods/...`에 있습니다.
- **사용 예:**

```
cd tools/devicemart
python dm_find.py "KY-035" "M3x5 렌치볼트"     # 상위 결과: 준비 기간 · 상태 · 가격 · 번호
python dm_lead.py 15959593,1399 "KY-035" "0.1uF"   # 특정 번호의 상태 · 준비 기간
python dm_page.py 15959593                    # 상품 페이지 제목 · 품절 표시 · 사양 문구
```

- **규칙:** 사용자에게 링크나 가격을 줄 때는 **이 스크립트로 확인한 것만** 줍니다. 확인하지 않은 것은 "확인 안 함"이라고 적습니다.

---

## 13. 알려진 함정

- **변수 이름 겹침:** 11장에 적은 `include` 변수 덮어쓰기입니다.
- **clash 검사를 중간에 끊을 때:** `hardware/cad/`에 `tmp*.scad`가 남습니다 (`.gitignore` 처리됨). 지워도 됩니다.
- **호퍼 높이:** `powder_hopper_top()`에 턱 높이 2가 빠져서 가루통이 호퍼를 2mm 파고든 적이 있습니다. 지금은 고쳤습니다. 높이 함수를 고치면 가루통 × 호퍼 겹침 검사로 확인하세요.
- **컵 꺼내는 길:** 컵이나 미끄럼관 높이를 바꾸면 `sweepL`·`sweepP` 검사가 깨질 수 있습니다.
- **알약 기둥 ±92:** 여기서 더 바깥으로 옮기면 상판 테두리를 파고듭니다.

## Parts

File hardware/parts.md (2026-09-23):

# 부품표

구매처는 모두 [디바이스마트](https://www.devicemart.co.kr)입니다. 가격은 2026-09 기준이고 부가세가 빠져 있습니다.

## 모터 · 구동

| 부품 | 수량 | 쓰는 곳 |
|---|---|---|
| JGA25-370 감속 DC 모터 6V 77RPM [SZH-GNP103] | 4 | 가루 스크류 |
| 28BYJ-48 스텝 모터 + ULN2003 드라이버 세트 [SZH-EKBL-007] | 4 (구매 3 + 아두이노 세트에 있던 1) | 알약 원판 |
| DRV8833 모터 드라이버 [VLT-MD012] | 2 (+여분 1) | 가루 모터 2개씩 |
| MCP23017 IO 확장 보드 [226702] | 1 | ESP32 → ULN2003 ×4 (I2C) |

## 센서

| 부품 | 수량 | 쓰는 곳 |
|---|---|---|
| 로드셀 1kg [VLT-LCS002] | 1 | 컵 무게 |
| HX711 [SZH-SSBH-016] | 1 | 로드셀 증폭 |
| 아날로그 홀 센서 KY-035 [VLT-ML007] | 4 | 알약 원판 원점 (센서 알맹이만 떼어 씀) |
| ND 원형 자석 8Ø×3t | 4 (최소 구매 10) | 알약 원판 |

## 전원 · 기판

| 부품 | 수량 | 쓰는 곳 |
|---|---|---|
| 아답터 5V 4A (2.1mm) | 1 | 전체 전원 |
| 터미널블럭 to DC 커넥터 [SZH-LC002] | 1 | 아답터 → 만능기판 |
| 만능기판 Half Size 89×52mm | 1 | DRV8833, 커패시터, 전원 분배 |
| 핀헤더소켓 1×40 | 2 | DRV8833 소켓, 점퍼 연결 |
| 2핀 터미널 블록 5.08 | 10 | 모터 선, 전원 |
| E/C 10V 1000µF | 3 (최소 구매 10) | DRV8833 전원 ×2, DC 잭 옆 ×1 |
| Mono Cap 0.1µF | 4 (최소 구매 10) | 가루 모터 단자 잡음 |
| 저항 4.7kΩ | 2 (최소 구매 30) | I2C 풀업 |
| 저항 10kΩ 1% | 1 (최소 구매 10) | nFAULT 풀업 |

## 선 · 나사

| 부품 | 수량 | 쓰는 곳 |
|---|---|---|
| 3색 점퍼용 단선 0.6파이 1m (빨강·검정·흰색 1m씩) | 6 | 모터 · HX711 · 홀 센서 (길이는 [wiring.md](wiring.md)) |
| F-F 점퍼 30cm | 1묶음 | ESP32 · MCP23017 · ULN2003 |
| 수축튜브 1.5파이 1m | 1 | 홀 센서 다리 납땜 |
| 둥근머리 렌치볼트 + 너트 키트 (340pcs) | 1 | M3x12 + 너트 8개 (가루 모터 띠) |
| 렌치볼트 M3x5 | 8 (최소 구매 10) | 알약 모터 |
| 스텐 렌치볼트 M5x15 | 2 (최소 구매 10) | 로드셀 고정 끝 |
| 스텐 렌치볼트 M4x12 | 2 (최소 구매 10) | 로드셀 쟁반 끝 |

## 따로 준비

- ESP32-DevKitC V4
- PLA 필라멘트 (Ender-3 SE)
- 컵 1개, 가루통 4개 (다이소, 바닥 한 변 85mm 이하)
- 케이블 타이, 인두

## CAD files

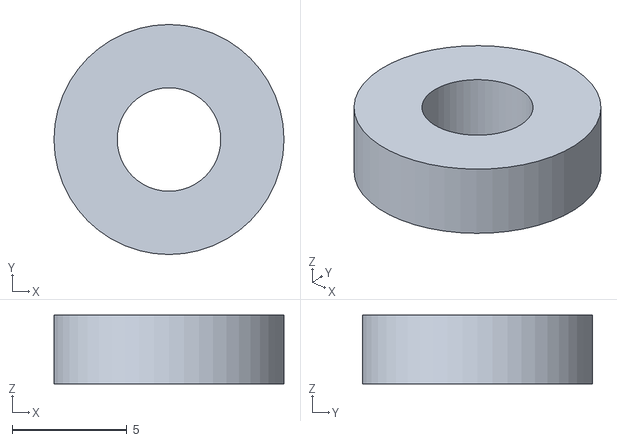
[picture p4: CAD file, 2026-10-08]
hardware/cad/stl/scale_spacer.stl
10.0 x 10.0 x 3.00

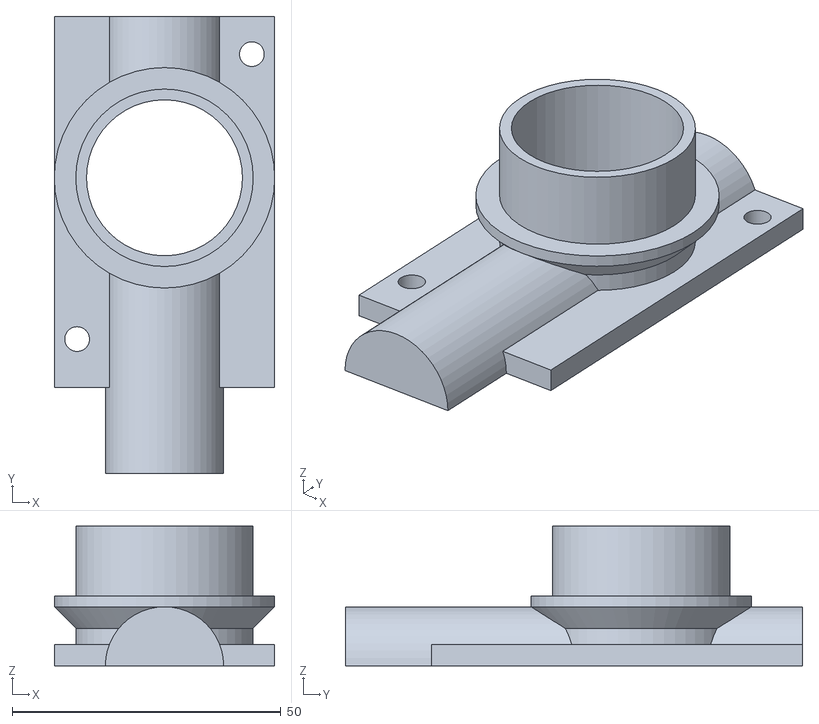
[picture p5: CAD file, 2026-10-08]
hardware/cad/stl/powder_top.stl
41.0 x 85.0 x 26.0

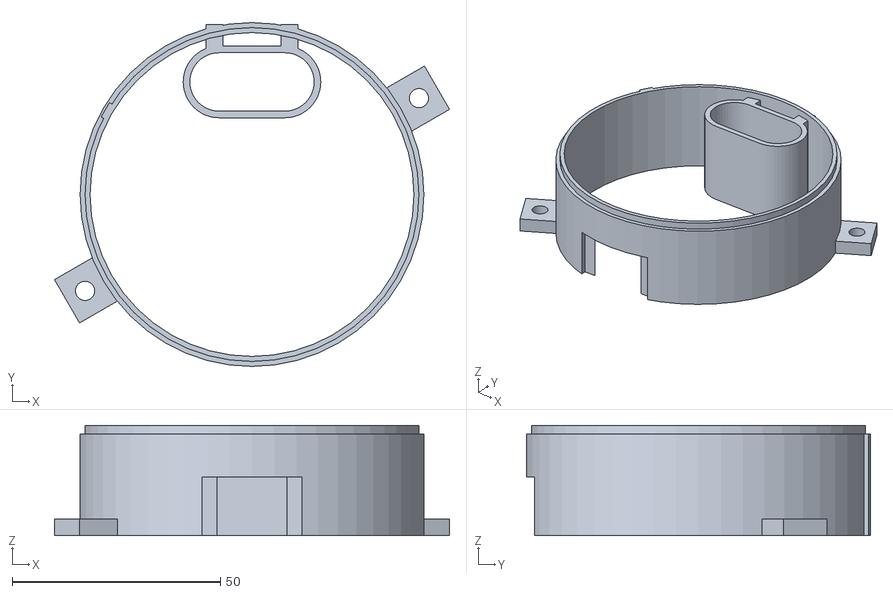
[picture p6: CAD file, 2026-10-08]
hardware/cad/stl/pill_skirt.stl
94.7 x 82.5 x 26.4

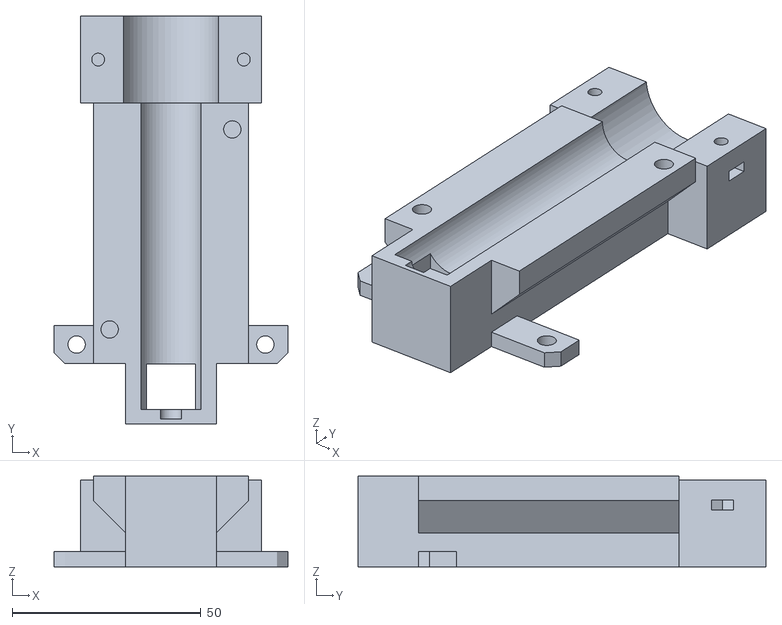
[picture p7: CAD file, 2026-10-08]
hardware/cad/stl/powder_block.stl
62.0 x 108.0 x 24.0

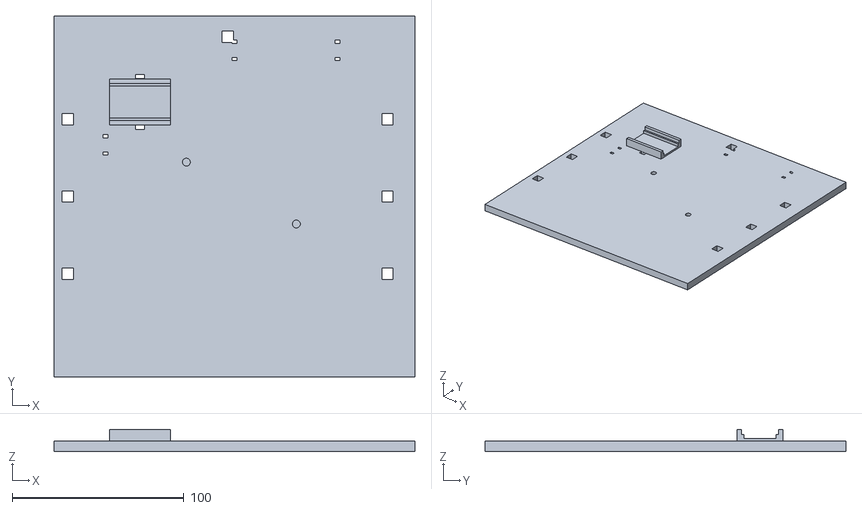
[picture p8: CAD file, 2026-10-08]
hardware/cad/stl/base_powder.stl
210.0 x 210.0 x 12.8

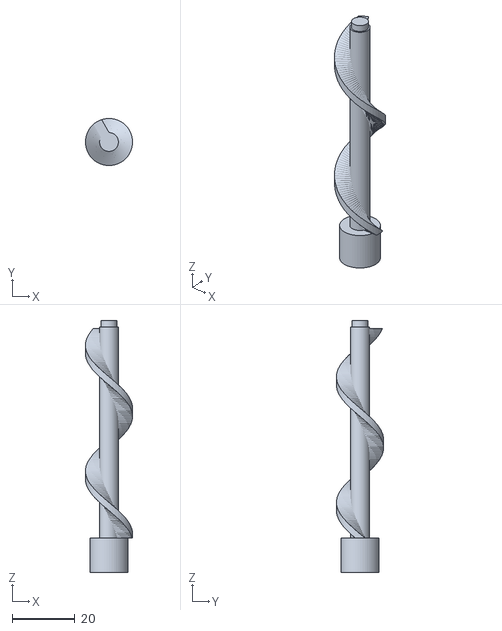
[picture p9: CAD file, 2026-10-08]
hardware/cad/stl/auger.stl
15.0 x 15.0 x 80.2

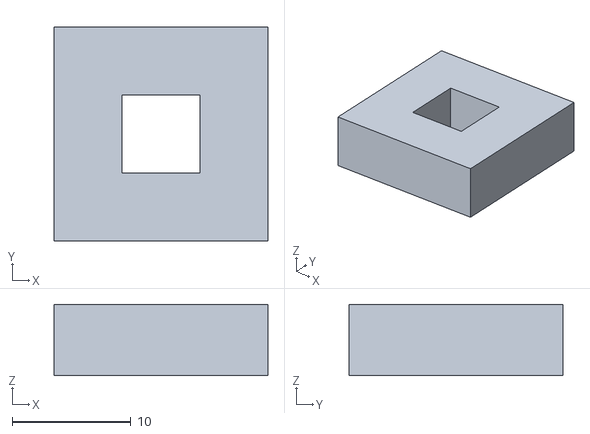
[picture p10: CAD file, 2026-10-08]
hardware/cad/stl/pegtest.stl
18.0 x 18.0 x 6.00

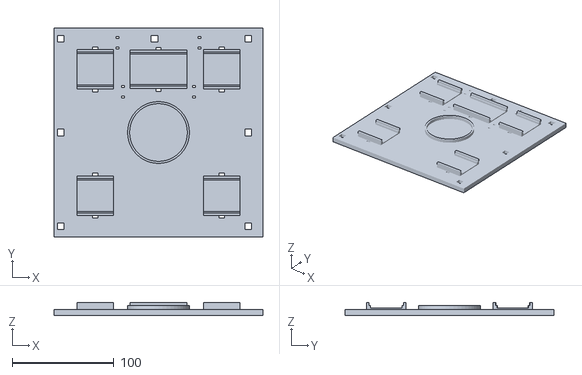
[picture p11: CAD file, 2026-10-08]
hardware/cad/stl/base_pill.stl
205.0 x 205.0 x 12.8

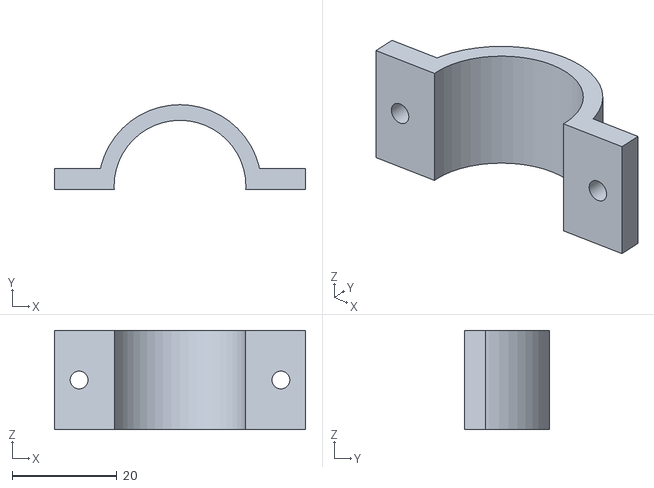
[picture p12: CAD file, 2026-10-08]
hardware/cad/stl/powder_strap.stl
48.0 x 16.2 x 19.0

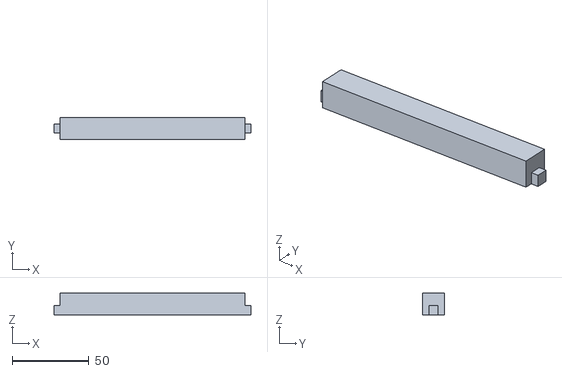
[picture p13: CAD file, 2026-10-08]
hardware/cad/stl/post.stl
128.0 x 14.0 x 14.0

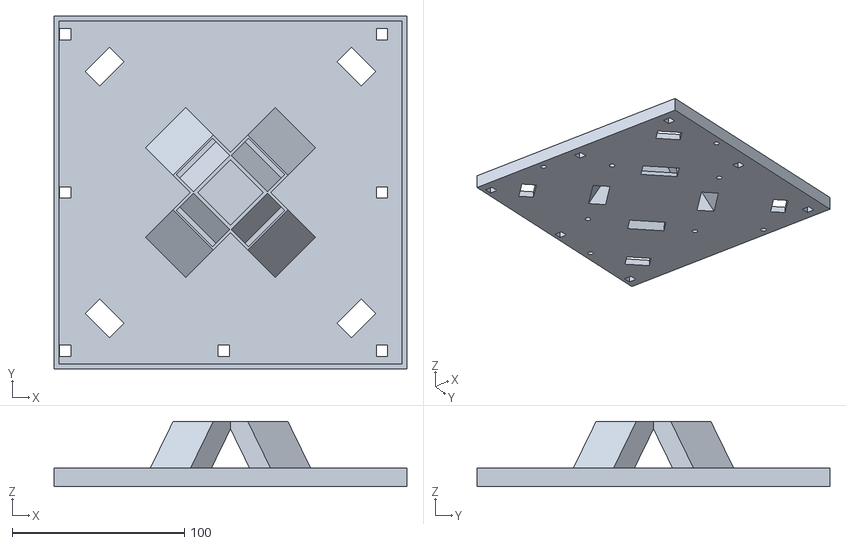
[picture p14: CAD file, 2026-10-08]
hardware/cad/stl/deck_pill.stl
205.0 x 205.0 x 38.0

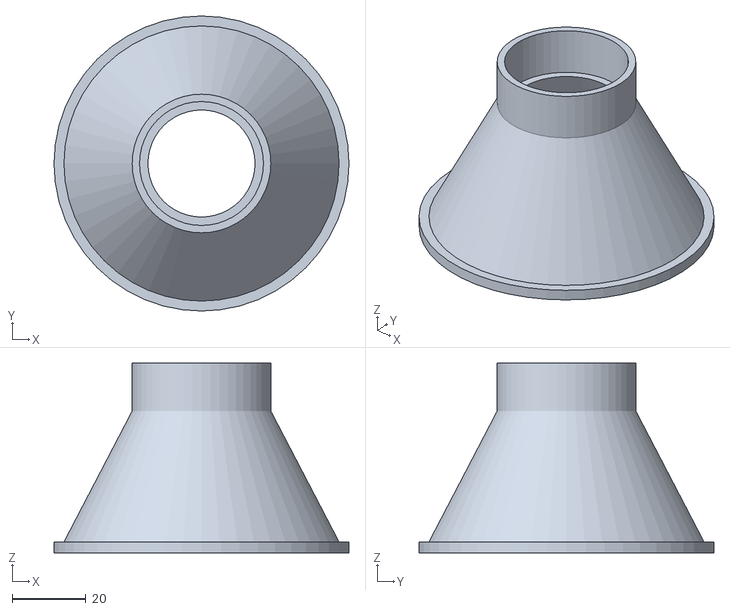
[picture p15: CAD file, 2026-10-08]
hardware/cad/stl/powder_hopper.stl
80.0 x 80.0 x 51.5

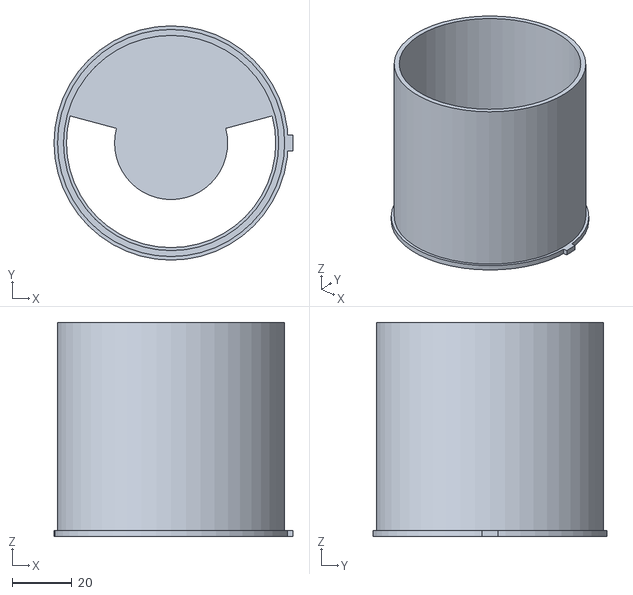
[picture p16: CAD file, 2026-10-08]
hardware/cad/stl/pill_cover.stl
80.3 x 78.7 x 72.0

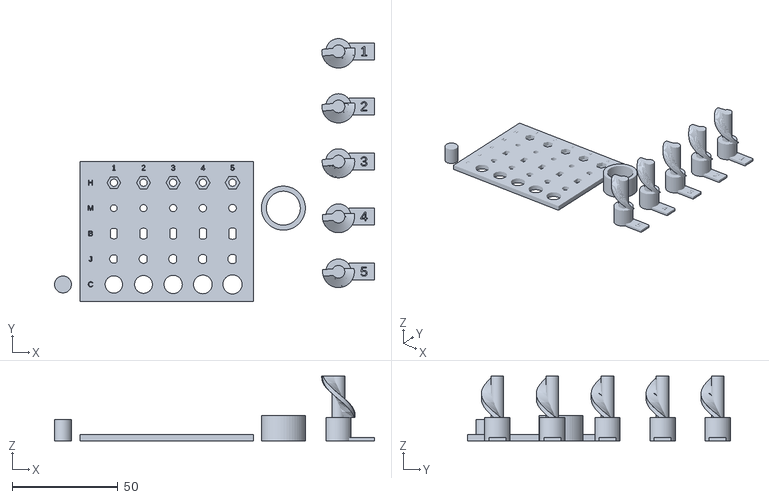
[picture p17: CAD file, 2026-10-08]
hardware/cad/stl/coupon.stl
151.0 x 124.0 x 30.5

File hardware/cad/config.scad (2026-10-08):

// =====================================================================
// 루틴 디스펜서 v2 (8칸: 가루 4 + 알약 4) · 공통 치수
// ---------------------------------------------------------------------
// 모든 부품 파일이 이 파일을 include 합니다. 숫자는 여기서만 고치세요.
// ★ = 추정치. 부품이 도착하면 측정표대로 재서 바꿉니다.
// 좌표: X 왼→오, Y 앞→뒤, Z 아래→위 (mm). 원점은 두 스테이션 사이, 바닥판 윗면 높이.
// 왼쪽 = 가루 스테이션, 오른쪽 = 알약 스테이션
// =====================================================================

$fn = 48;

// ---- 프린터 공차 (공차 쿠폰으로 확정) --------------------------------
clear      = 0.3;    // 끼워 맞춤 한쪽 여유 (쿠폰 C줄 3번으로 확정)
byj_d_clear = 0.15;  // 28BYJ 축 ↔ 원판 D구멍 여유 (쿠폰 B줄 4번으로 확정)
jga_d_clear = 0.15;  // ★ JGA 축 ↔ 스크류 허브 D구멍 여유 (쿠폰 J줄, 모터 오면 확정)
m3_hole    = 3.4;    // ★ M3 나사가 헐겁게 지나가는 구멍
m3_nut_af  = 5.8;    // ★ M3 너트 맞변 거리 + 여유 (육각 주머니)
m3_nut_t   = 2.7;    // ★ M3 너트 두께 + 여유
m3_head_d  = 6.2;    // 렌치볼트 머리 지름 + 여유
auger_gap  = 0.5;    // 스크류 날개 ↔ 관 벽 한쪽 틈. 스크류 지름만 바뀜 (관 16 고정)
                     // 좁히면 덜 새지만 가루가 끼어 모터가 멈출 수 있음. 가루 시험 전엔 0.5 유지

// ---- 나사 대신 쓰는 것 ------------------------------------------------
// 핀: 출력한 작은 원기둥. 구멍에 떨어뜨려 넣고 부품을 얹으면 자리가 잡힘 (무게로 눌림)
pin_d   = 4;
pin_len = 6.5;
pin_hole = pin_d + 2*clear;
// 기둥 끝 네모 돌기: 바닥판·상판의 네모 구멍에 끼움
peg_w = 6;  peg_h = 4;
peg_hole = peg_w + 2*clear;

// ---- 가루 모터: JGA25-370 6V 77RPM (상품 치수도 기준) ------------------
jga_gear_d    = 25;    // 감속기 지름 (치수도)
jga_gear_len  = 23;    // 감속기 길이 — 77RPM 은 23 (치수도 표)
jga_motor_d   = 24.4;  // 모터 몸통 지름 (치수도)
jga_motor_len = 30.8;  // 모터 몸통 길이 (치수도)
jga_term_len  = 4;     // 뒤쪽 단자 (치수도)
jga_shaft_d   = 4;     // 축 지름 (치수도)
jga_shaft_flat= 3.5;   // 축 D컷 (치수도)
jga_shaft_len = 11.5;  // 감속기 앞면 → 축 끝 (치수도)
jga_boss_d    = 7;     // 앞면 돌기 (치수도)
jga_boss_h    = 2.5;   // (치수도)
jga_len       = jga_gear_len + jga_motor_len + jga_term_len;

// ---- 알약 모터: 28BYJ-48 --------------------------------------------
// 출처: 제조사 도면 (components101 28BYJ-48 dimensions) + 사용자 실측 (2026-10-04)
byj_body_d    = 28;    // 도면 Ø28
byj_body_h    = 19.4;  // 실측 19.4 (도면 19)
byj_ear_span  = 35;    // 도면 35±0.2, 실측 (안쪽 벽 + 바깥쪽 벽) / 2 로 확인
byj_ear_hole  = 4.2;   // 도면 Ø4.2
byj_shaft_off = 8;     // 도면: 몸통 중심 → 축 8
byj_shaft_d   = 5;     // 도면 Ø5
byj_shaft_flat= 3;     // 도면: 양쪽 D컷 폭 3
byj_shaft_len = 8.5;   // 도면: 몸통 윗면 → 축 끝 10, 돌기 1.5 → 돌기 윗면에서 8.5
byj_flat_len  = 6;     // 도면: D컷 길이 6 (축 끝에서부터). 그 아래는 둥근 축
byj_ear_t     = 0.8;   // 고정 귀 두께 (도면에 없음, 설계에서 안 씀)
byj_boss_d    = 9;     // 도면 Ø9
byj_boss_h    = 1.5;   // 도면 1.5
byj_cover_w   = 14.6;  // 도면: 파란 전선 덮개 폭
byj_cover_r   = 17;    // 도면: 몸통 중심 → 덮개 끝 17 (실측: 몸통 밖으로 3)
byj_conn_w    = 15;    // 실측: 흰색 커넥터(JST XH 5핀) 폭
byj_conn_t    = 5.5;   // 실측: 두께
byj_conn_l    = 8;     // 실측: 길이 (전선 방향)

// ---- 로드셀 1kg (VLT-LCS002, 상품 치수도 기준) ------------------------
lc_l      = 80;        // 치수도
lc_w      = 12.7;      // 치수도
lc_h      = 12.7;      // 치수도
lc_holes  = [5, 20];   // 양 끝에서 구멍까지 (치수도: 15 간격, 안쪽 40 간격)
// 전선이 나오는 끝 = M5 두 개 = 고정 끝(받침). 반대 끝 = M4 두 개 = 쟁반.
lc_fix_bolt_d  = 5.5;  lc_fix_head_d  = 9.2;  lc_fix_head_h  = 5.8;   // M5x15 (머리 자리 천장이 처져도 머리가 안 튀어나오게 0.8 여유)
lc_load_bolt_d = 4.5;  lc_load_head_d = 7.6;  lc_load_head_h = 4.2;   // M4x12

// ---- 컵 (다이소, 미정) ------------------------------------------------
cup_bottom_d = 55;     // ★ 바닥 지름
cup_top_d    = 75;     // ★ 입구 지름 (가루 출구 4개가 이 안에 떨어져야 함)
cup_h        = 75;     // ★ 높이
function cup_d_at(h) = cup_bottom_d + (cup_top_d - cup_bottom_d) * h / cup_h;

// ---- 알약 -------------------------------------------------------------
// 최대 알약: 모듈 몸체(치마·바닥·덮개·알약 상판 미끄럼관)를 이 크기로 만듦. 한 번만 뽑음.
pill_max_l = 26;       // ★ 오메가3 1000mg 연질캡슐급 (흔히 약 25 × 10~11)보다 조금 크게
pill_max_w = 11;       // ★
pill_max_t = 11;       // ★ 연질캡슐은 단면이 둥글어서 두께 = 폭
// 칸에 넣을 알약: 원판 칸·원판 두께·받침판을 이 크기로 만듦. 알약을 바꾸면 원판·받침판만 다시 뽑음.
pill_l = 18.2;         // 실측: 종근당 멀티비타민 길이
pill_w = 9.2;          // 실측: 폭
pill_t = 5.9;          // 실측: 누웠을 때 두께

// ---- 전자부품 ----------------------------------------------------------
pb_w = 89;  pb_d = 52; pb_t = 1.6;       // 만능기판 (상품명 치수) · 두께 ★
esp_w = 54.4; esp_d = 27.9; esp_t = 1.6; // ★ ESP32-DevKitC V4
dcj_d = 11;  dcj_l = 30;                 // ★ DC 잭 몸통 지름·길이
uln_w = 35;  uln_d = 33; uln_t = 1.6;    // ULN2003 보드 (상품 설명 35×33) · 두께 ★
mcp_w = 55;  mcp_d = 32; mcp_t = 1.6;    // ★ MCP23017 보드
hx_w  = 35;  hx_d  = 21; hx_t  = 1.6;    // ★ HX711 보드
hall_w = 4.2; hall_l = 3.2; hall_t = 1.6; // ★ 49E 홀 센서 알맹이 (TO-92S). KY-035 보드에서 떼어 다리에 단선 납땜
mag_d = 8;   mag_t = 3;                  // 원판 원점 자석 (ND 8Ø×3t)

// ---- 뼈대 (스테이션마다 바닥판 + 상판 + 기둥) ------------------------
base_t   = 6;          // 바닥판 두께 (아랫면에 너트 주머니)
deck_t   = 5;          // 상판 두께
deck_z   = 120;        // 상판 아랫면 높이
deck_top = deck_z + deck_t;
rim_h    = 6;          // 상판 테두리 (아래로)
rim_w    = 3;
post_w   = 14;

cupP  = [-110, 0];     // 가루 스테이션 중심 = 가루 컵 중심
cupL  = [ 105, 0];     // 알약 스테이션 중심 = 알약 컵 중심
sizeP = [210, 210];    // 가루 스테이션 판 크기
sizeL = [205, 205];    // 알약 스테이션 판 크기
// 기둥: 모듈 발판·모터 아래를 피하고, 앞쪽(-Y)은 컵을 꺼내는 길이라 비움
postsP = [for (p = [[-93,-45],[93,-45],[-93,45],[93,45],[-93,0],[93,0],[0,93]]) [cupP[0]+p[0], cupP[1]+p[1]]];
postsL = [for (p = [[-92,-92],[92,-92],[-92,92],[92,92],[-92,0],[92,0],[0,92]]) [cupL[0]+p[0], cupL[1]+p[1]]];
ctrl_c    = [cupL[0], cupL[1] + sizeL[1]/2 + 50];   // 제어함 (알약 스테이션 뒤, 탁자 위)
ctrl_size = [190, 90];

// ---- 배치 --------------------------------------------------------------
powder_d   = 13;                 // 컵 중심 → 가루 모듈 출구 끝면
powder_a   = [45, 135, 225, 315];// 가루 모듈 방향 (X자)
pill_s     = 51;                // 알약 모듈 중심의 X·Y 거리 (2×2)

// ---- 출력 영역 (Ender-3 SE) ------------------------------------------
bed = [220, 220, 250];

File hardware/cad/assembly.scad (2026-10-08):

// =====================================================================
// 전체 조립 미리보기 + 겹침 검사용 배치 (8칸)
// ---------------------------------------------------------------------
// OpenSCAD 에서 이 파일을 "파일 → 열기"로 여세요 (복사해 붙이면 include 를 못 찾음).
// show = "all"   : 전체 조립 (F5)
// show = 부품 이름 : 그 부품만 조립 위치에 (check.py 가 씀)
// =====================================================================
include <config.scad>
include <lib.scad>
include <layout.scad>
use <powder.scad>
use <pill.scad>
use <scale.scad>
use <electronics.scad>
use <frame.scad>

show = "all";
bin_w = 85;       // ★ 가루통 바닥 한 변 (다이소 용기)
bin_h = 150;      // ★

lift_out = 4.5;
module cup_sweep(xy, z0) {
    hull() { cup_ghost(xy, z0 + 0.6); cup_ghost(xy, z0 + lift_out); }
    hull() { cup_ghost(xy, z0 + lift_out); cup_ghost(add2(xy, [0, -150]), z0 + lift_out); }
}

module piece(name) {
    if (name == "baseP")  baseP();
    if (name == "deckP")  deckP();
    if (name == "baseL")  baseL();
    if (name == "deckL")  deckL();
    if (name == "postsP") for (p = postsP) translate([p[0], p[1], 0]) post();
    if (name == "postsL") for (p = postsL) translate([p[0], p[1], 0]) post();
    for (i = [0:3]) {
        if (name == str("powder", i))  at_powder(i) { powder_block(); powder_top(); powder_strap(); }
        if (name == str("hopper", i))  at_powder(i) powder_hopper();
        if (name == str("auger", i))   at_powder(i) auger_placed();
        if (name == str("motor", i))   at_powder(i) jga_ghost();
        if (name == str("bin", i))     at_powder(i) translate([0, powder_collar_y(), powder_hopper_top()])
                                           rotate(-(powder_a[i] - 90)) translate([-bin_w/2, -bin_w/2, 0]) cube([bin_w, bin_w, bin_h]);
        if (name == str("pill", i))    at_pill(i) { pill_skirt(); pill_floor(); }
        if (name == str("disk", i))    at_pill(i) translate([0, 0, pill_disk_z()]) rotate(pill_rest_a()) pill_disk();
        if (name == str("pspacer", i)) at_pill(i) translate([0, 0, pill_well_z()]) pill_spacer();
        if (name == str("hall", i))    at_pill(i) hall_ghost();
        if (name == str("pilltop", i)) at_pill(i) translate([0, 0, pill_ledge_z()]) pill_cover();
        if (name == str("byj", i))     at_pill(i) byj_ghost(pill_rest_a());
    }
    if (name == "scale")    { pedestal(); tray(); spacers_placed(); }
    if (name == "loadcell") loadcell_ghost();
    if (name == "cupP")     cup_ghost(cupP, cup_z_powder());
    if (name == "cupL")     cup_ghost(cupL, 0);
    // 컵 꺼내는 길: 4.5mm 들어 올린 뒤 앞(-Y)으로 150mm
    if (name == "sweepP")   cup_sweep(cupP, cup_z_powder());
    if (name == "sweepL")   cup_sweep(cupL, 0);
    if (name == "ctrl")     ctrl_placed();
}

if (show == "all") {
    color("Beige") { piece("baseP"); piece("baseL"); }
    color("Beige", 0.7) { piece("deckP"); piece("deckL"); }
    color("Linen") { piece("postsP"); piece("postsL"); }
    for (i = [0:3]) {
        color("Tan") piece(str("powder", i));
        color("Khaki", 0.7) piece(str("hopper", i));
        color("Peru") piece(str("auger", i));
        color("SteelBlue") piece(str("pill", i));
        color("Gold") piece(str("disk", i));
        color("Orange") piece(str("pspacer", i));
        color("White", 0.5) piece(str("pilltop", i));
        %piece(str("motor", i)); %piece(str("byj", i)); %piece(str("bin", i)); %piece(str("hall", i));
    }
    color("DimGray") piece("scale");
    color("SlateGray") piece("ctrl");
    %piece("loadcell"); %piece("cupP"); %piece("cupL");
} else {
    piece(show);
}

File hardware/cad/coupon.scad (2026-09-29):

// =====================================================================
// 공차 쿠폰 — 큰 부품보다 먼저 출력 (약 30~40분)
// ---------------------------------------------------------------------
// 1줄: 8mm 핀 구멍 (여유 0.1~0.5) → 핀이 "돌지만 흔들리지 않는" 칸 = clear
// 2줄: JGA25-370 축 D구멍 → 모터 축이 "손으로 꽉 끼는" 칸 (스크류 허브)
// 3줄: 28BYJ-48 축 D구멍 → 같은 기준 (알약 원판 허브)
// 4줄: M3 구멍 3.2~3.6 → 나사가 "힘 없이 지나가는" 가장 작은 칸 = m3_hole
// 5줄: M3 너트 주머니 5.6~6.0 → 너트가 "눌러야 들어가고 안 빠지는" 칸 = m3_nut_af
// 오른쪽: 관 고리 1개 + 틈별 스크류 조각 5개(G줄) → 걸림 없이 도는 가장 좁은 칸 + 한 칸 = auger_gap
// =====================================================================
include <config.scad>
include <lib.scad>
use <powder.scad>

cs   = [0.1, 0.2, 0.3, 0.4, 0.5];
dcs  = [0.0, 0.05, 0.1, 0.15, 0.2];
m3s  = [3.2, 3.3, 3.4, 3.5, 3.6];
nuts = [5.6, 5.7, 5.8, 5.9, 6.0];
pitch = 14;
rows_y = [8, 20, 32, 44, 56];

module label(s, x, y) translate([x, y, 2.4]) linear_extrude(1) text(s, size = 2.6, halign = "center", valign = "center");

difference() {
    cube([len(cs) * pitch + 12, 66, 3]);
    for (i = [0 : 4]) {
        x = 16 + i * pitch;
        translate([x, rows_y[0], -1]) cylinder(d = 8 + 2*cs[i], h = 5);
        translate([x, rows_y[1], -1]) linear_extrude(5) dshaft_jga2d(dcs[i]);
        translate([x, rows_y[2], -1]) linear_extrude(5) dshaft_byj2d(dcs[i]);
        translate([x, rows_y[3], -1]) cylinder(d = m3s[i], h = 5);
        translate([x, rows_y[4], 3 - m3_nut_t]) cylinder(d = nuts[i] / cos(30), h = 5, $fn = 6);
        translate([x, rows_y[4], -1]) cylinder(d = 3.4, h = 5);
    }
    for (r = [0 : 4]) label(str(["C", "J", "B", "M", "H"][r]), 5, rows_y[r]);
    for (i = [0 : 4]) label(str(i + 1), 16 + i * pitch, 63);
}
// 끼워 볼 8mm 핀
translate([-8, 8, 0]) cylinder(d = 8, h = 10);
// G줄: 틈별 스크류 조각 5개 (관 16 고정, 스크류 지름만 다름). 번호표 5~1 = 틈 0.5~0.1
// 고리(아래)에 끼워 끝까지 걸림 없이 도는 것 중 가장 좁은 칸 → auger_gap 은 그보다 한 칸 넓게
gaps = [0.5, 0.4, 0.3, 0.2, 0.1];
for (i = [0 : len(gaps) - 1]) translate([len(cs) * pitch + 52, 14 + i * 26, 0]) {
    intersection() {
        auger(powder_tube_id() - 2*gaps[i]);
        translate([-10, -10, 0]) cube([20, 20, 30.5]);
    }
    difference() {
        translate([5, -4, 0]) cube([12, 8, 1.6]);
        translate([12, 0, 0.8]) linear_extrude(1) text(str(round(gaps[i] * 10)), size = 4.5, halign = "center", valign = "center");
    }
}
// 관 고리 (실제 관 안지름과 같음)
translate([len(cs) * pitch + 26, 44, 0]) difference() {
    cylinder(d = powder_tube_id() + 2*2.4, h = 12);
    translate([0, 0, -1]) cylinder(d = powder_tube_id(), h = 14);
}

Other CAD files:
hardware/cad/stl/scale_tray.stl
hardware/cad/stl/pill_spacer.stl
hardware/cad/stl/ctrl_plate.stl
hardware/cad/stl/pins.stl
hardware/cad/electronics.scad
hardware/cad/frame.scad
hardware/cad/layout.scad
hardware/cad/lib.scad
hardware/cad/pill.scad
hardware/cad/powder.scad
hardware/cad/scale.scad
hardware/cad/stl/deck_powder.stl
hardware/cad/stl/pill_disk.stl
hardware/cad/stl/pill_floor.stl
hardware/cad/stl/scale_pedestal.stl

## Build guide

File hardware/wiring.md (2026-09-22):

# stackdose 배선표 (8칸)

전원은 **5V 4A 어댑터 하나**입니다. 모든 GND는 하나로 묶습니다.
배선은 모두 **제어판의 만능기판**으로 모입니다. ESP32는 만능기판 옆 받침에 올려 두고 F-F 점퍼(30cm)로 만능기판 핀헤더와 연결합니다.

## 배치 (어디에 무엇이 있나)

| 부품 | 위치 |
|---|---|
| 만능기판 (DRV8833 ×2, 커패시터, 전원 분배), ESP32, DC 잭 | 제어판 (알약 스테이션 뒤, 탁자 위) |
| ULN2003 ×4 | 알약 바닥판, 알약 모듈 4개 각각의 바로 아래 |
| MCP23017 | 알약 바닥판 뒤쪽 가운데 |
| HX711 | 가루 바닥판 뒤쪽 왼편 (로드셀 옆) |
| 홀 센서 ×4 | 알약 모듈 바닥 밑 홈 (원판 자석 바로 아래) |

## 전원

| 출발 | 도착 | 비고 |
|---|---|---|
| 5V 어댑터 → DC 잭 | 만능기판 5V 레일 / GND 레일 | 터미널 블록 |
| 5V 레일 | ESP32 `5V` 핀 | ⚠ USB로 코드를 올릴 때는 이 선을 뽑으세요 |
| 5V 레일 | DRV8833 #1·#2 `VCC` | 모터 전원 |
| 5V 레일 | ULN2003 #1~#4 `+` | 알약 모터 전원 (점퍼로 MCP 옆까지 한 가닥, 거기서 4갈래) |
| ESP32 `3V3` | MCP23017 `VCC`·`RESET`, HX711 `VCC`, 홀 센서 4개 `+`, DRV8833 #1·#2 `EEP` | EEP를 안 이으면 DRV8833이 잠들어 **모터가 안 돕니다**. MCP23017 `RESET`도 3V3에 이어야 동작합니다 (보드에 이미 연결돼 있으면 생략 ★) |
| 1000µF 10V ×3 | DRV8833마다 `VCC`–`GND` 1개, DC 잭 옆 1개 | 긴 다리 = +, 띠 표시 = − |
| 100nF ×4 | 가루 모터마다 두 단자 사이에 납땜 | 모터 잡음이 ESP32를 리셋시키는 것을 막음 |
| 4.7kΩ ×2 | SDA–3V3, SCL–3V3 | I2C 풀업 (MCP 보드에 이미 있으면 생략해도 됨) |
| 10kΩ ×1 | nFAULT–3V3 | 풀업 |

## ESP32 핀 배정

부팅에 영향을 주는 핀(0, 2, 12, 15), 메모리 칩 핀(6~11), USB 통신 핀(1, 3)은 쓰지 않았습니다.
16·17번은 ESP32 모듈 종류(WROVER)에 따라 쓸 수 없어서 피했습니다.

| ESP32 | 연결 | 용도 |
|---|---|---|
| GPIO21 | MCP23017 `SDA` | I2C |
| GPIO22 | MCP23017 `SCL` | I2C |
| GPIO18 | HX711 `DT` | 무게 데이터 |
| GPIO33 | HX711 `SCK` | 무게 클럭 |
| GPIO25 | DRV8833 #1 `AIN1` | 가루 1 |
| GPIO26 | DRV8833 #1 `AIN2` | 가루 1 |
| GPIO27 | DRV8833 #1 `BIN1` | 가루 2 |
| GPIO13 | DRV8833 #1 `BIN2` | 가루 2 |
| GPIO32 | DRV8833 #2 `AIN1` | 가루 3 |
| GPIO23 | DRV8833 #2 `AIN2` | 가루 3 |
| GPIO4  | DRV8833 #2 `BIN1` | 가루 4 |
| GPIO19 | DRV8833 #2 `BIN2` | 가루 4 |
| GPIO5  | DRV8833 #1·#2 `ULT`(nFAULT) 묶어서 | 드라이버 오류 감지 (10kΩ 풀업. 부팅 때 HIGH여야 하는 핀이라 풀업과 맞음) |
| GPIO36 (VP) | 홀 센서 1 `S` | 알약 1 원점 (아날로그) |
| GPIO39 (VN) | 홀 센서 2 `S` | 알약 2 원점 |
| GPIO34 | 홀 센서 3 `S` | 알약 3 원점 |
| GPIO35 | 홀 센서 4 `S` | 알약 4 원점 |

홀 센서 4개는 모두 ADC1 핀이라 와이파이를 켜도 읽힙니다. 자석이 없을 때 약 1.65V이고, 자석이 오면 위나 아래로 크게 움직입니다. 기준값은 처음에 한 번 재서 코드에 넣습니다.

## MCP23017 → ULN2003 (알약 모터 4개)

주소는 0x20입니다 (A0·A1·A2를 GND에 연결).

| MCP23017 | ULN2003 | 알약 칸 |
|---|---|---|
| GPA0~GPA3 | #1 `IN1~IN4` | 알약 1 |
| GPA4~GPA7 | #2 `IN1~IN4` | 알약 2 |
| GPB0~GPB3 | #3 `IN1~IN4` | 알약 3 |
| GPB4~GPB7 | #4 `IN1~IN4` | 알약 4 |

28BYJ-48은 ULN2003 보드의 흰 커넥터에 그대로 꽂습니다. 배출하지 않을 때는 네 핀을 모두 LOW로 둡니다.

## 선 길이 · 종류 (20% 여유 포함)

| 구간 | 가닥 | 한 가닥 길이 | 선 | 지나는 길 |
|---|---|---|---|---|
| 가루 모터 1·2 (뒤쪽) → 만능기판 | 2 × 2 | 45cm | 단선 0.6 | 모터 밑 상판 구멍(Ø9) → 가장 가까운 기둥 따라 아래로 → 가루 바닥판 뒤 가장자리 케이블 타이 → 제어판 |
| 가루 모터 3·4 (앞쪽) → 만능기판 | 2 × 2 | 65cm | 단선 0.6 | 같은 길, 바닥판 옆 가장자리를 따라 뒤로 |
| 로드셀 → HX711 | 4 | 로드셀 기본 선 (약 20cm ★) | — | 바로 옆. HX711 `E+ E− A− A+` 에 납땜 (빨강 검정 하양 초록이 보통, 색은 확인) |
| HX711 → 만능기판 | 4 | 55cm | 단선 0.6 | 가루 바닥판 뒤 가장자리 → 알약 바닥판 뒤 → 제어판 |
| 홀 센서 (뒤쪽 2개) → 만능기판 | 3 × 2 | 45cm | 단선 0.6 | 모듈 바닥 홈 → 치마 안 → 상판 전선 구멍(20×12) → 기둥 따라 아래 → 제어판 |
| 홀 센서 (앞쪽 2개) → 만능기판 | 3 × 2 | 60cm | 단선 0.6 | 같은 길 |
| 28BYJ-48 → ULN2003 | (모터 기본 선) | 약 25cm ★ | — | 상판 전선 구멍 → 바로 아래 ULN2003 |
| ULN2003 ×4 → MCP23017 | 4 × 4 + 전원 | 30cm | F-F 점퍼 | 알약 바닥판 위, 케이블 타이 구멍 따라 |
| MCP23017 → 만능기판 (SDA, SCL, 3V3, GND, 5V) | 5 | 30cm (2개 이어 60cm) | F-F 점퍼 → 제어판에서 만능기판 핀헤더 | 알약 바닥판 뒤 가장자리 |
| ESP32 → 만능기판 | 약 20 | 30cm | F-F 점퍼 | 제어판 위 |

단선은 "3색 점퍼용 단선 0.6파이 [1미터단위]"입니다. 상품 설명에 따르면 1개를 사면 빨강·검정·흰색이 1m씩 꼬여서 옵니다.

| 색 | 쓰는 곳 | 필요 길이 |
|---|---|---|
| 빨강 | 모터 +, HX711 VCC, 홀 센서 + | 약 4.9m |
| 검정 | 모터 −, HX711 GND, 홀 센서 − | 약 4.9m |
| 흰색 | HX711 DT·SCK, 홀 센서 S | 약 3.2m |

가장 많이 쓰는 색이 약 4.9m라서 **6개**를 사세요 (색마다 6m). 상품 설명에 "부분 절단될 수 있다"고 되어 있어서 1m를 더 잡았습니다.
홀 센서 선은 세 가닥 꼬인 그대로 쓰면 됩니다.

⚠ **ESP32는 점퍼를 먼저 다 꽂고 받침에 올리세요.** 받침은 긴 두 변이 열려 있어서, 꽂은 선이 옆으로 빠져나갑니다. 받침에 먼저 올리면 밑의 핀에 손이 안 들어갑니다.

## 한 번에 하나만

5V 4A 안에서 돌리기 위해 코드에서 **한 번에 모터 하나만** 돌립니다.

| 부하 | 전류 (추정) |
|---|---|
| JGA25-370 하나가 막혀서 멈춘 경우 | 약 1.1A |
| 28BYJ-48 하나 | 약 0.25A |
| ESP32 (와이파이 전송 순간) | 약 0.5A |
| **합계** | **약 1.9A** |

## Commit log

2026-09-22 stackdose: 3D 설계, 배선, 부품표
    [assembly.scad, auger.stl, base_pill.stl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]
2026-09-23 웹 1단계: SQLite 스키마, /slots API, React 화면
2026-09-29 3D 설계 검수 반영, 쿠폰 G줄(스크류 틈 시험) 추가
    - 관 안지름 16 고정, 스크류 지름 = 16 - 2*auger_gap (틈 바꿀 땐 스크류만 재출력)
    - 쿠폰: 관 고리를 실제 tube_id 로, 틈 0.5~0.1 스크류 조각 5개
    - 스크류 끝 핀 구멍 앞 벽 0.5 -> 1.3 (endcap_t 3.8, L 85 유지)
    - 저울 M5 머리 자리 깊이 5.2 -> 5.8
    - pill rim_h/rim_w -> pill_rim_* (config 값 덮어쓰기 제거)
    - D구멍 여유 byj_d_clear / jga_d_clear 분리, 숫자로 적힌 곳 변수화
    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
    [auger.stl, base_pill.stl, base_powder.stl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]
2026-09-29 웹: /presets API (프리셋별 항목 묶기), 프론트 프리셋 연동
2026-09-29 문서: 컵은 두 개 (가루 컵은 저울 위, 알약 컵은 알약 스테이션)
2026-09-29 웹: 담기 요청 API (POST /presets/{no}/dispense), dispenses 테이블
    - 없는 프리셋은 404, 있으면 dispenses 에 requested 로 기록하고 요청 id 반환
    - 프론트 담기 버튼이 API 호출
2026-09-30 웹: 담기 요청 조회 API (GET /dispenses/{id}, 없으면 404)
2026-09-30 기둥 돌기 시험 조각(pegtest), 스크류 틈 G줄은 선택 사항으로
    - pegtest: 판과 같은 peg_holes() 로 뚫은 18x18 조각. 큰 판 전에 기둥 돌기 맞춤 확인
    - auger_gap 0.5 유지. 보급형 프린터라 헐렁한 게 정상, 새는 가루는 폐루프·역회전으로
    [auger.stl, base_pill.stl, base_powder.stl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]
2026-09-30 웹: 기계용 API (GET /device/next, POST /dispenses/{id}/start), 가상 디스펜서 시작
    - /device/next: requested 중 가장 오래된 요청, 없으면 null
    - /dispenses/{id}/start: requested -> running. 없으면 404, 이미 가져갔으면 409 (rowcount 로 동시 요청 방지)
    - virtual_device.py: 다음 일감 조회만 (다음: start 까지 호출)
2026-10-08 알약 모듈: 28BYJ 치수 확정, 몸체는 최대 알약 / 원판·받침판은 칸에 넣을 알약
    - 28BYJ: 제조사 도면 + 실측 (높이 19.4, 축 길이 8.5, 귀 간격 35), 파란 덮개·커넥터 실측 반영
    - 커넥터가 전선 창·상판 구멍보다 크면 렌더 실패 (assert)
    - 몸체(치마·바닥·덮개·미끄럼관) = 최대 알약 26x11x11 (오메가3급, 추정)
    - 원판 칸·두께 = 칸에 넣을 알약 (종근당 멀티비타민 실측 18.2x9.2x5.9)
    - 받침판(pill_spacer) 추가: 얇은 알약일 때 원판 윗면 높이를 맞춤, 키로 출구 정렬
    - 한 칸에 한 알 검사 (겹침·세움 두 알이면 렌더 실패)
    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
    [assembly.scad, auger.stl, base_pill.stl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]
2026-10-08 웹: 완료 보고 API (POST /dispenses/{id}/finish), 가상 디스펜서 폴링
    - finish: running -> done. 없으면 404, running 이 아니면 409
    - virtual_device.py: 2초마다 다음 일감 확인, start 200 일 때만 담는 척 후 finish
    - main.py / virtual_device.py 주석
2026-10-13 제어판: ESP32 보드 실측 반영 (기판 48.1×27.9×1.8, 안테나 자리)
2026-10-13 웹: finish 409 메시지 수정
2026-10-13 펌웨어: ESP-IDF 프로젝트, Wi-Fi 연결, 서버에 HTTP GET (/device/next)
2026-10-14 펌웨어: 응답 본문 받기(http_request), JSON 값 꺼내기(json_get)
2026-10-14 HANDOFF: 부품 주문 완료 (2026-10-13)
2026-10-14 펌웨어: 2초마다 일감 폴링, start 성공 시에만 finish (virtual_device.py 대체)
2026-10-15 웹: /device/next 에 칸별 담을 양 amounts[8] 추가
2026-10-15 펌웨어: 일감 응답에서 amounts[8] 읽기
2026-10-16 웹: 프론트 mock 제거, 기계 상태 · 담기 현황 · 취소 · 프리셋/칸 편집 API
2026-10-16 펌웨어: 부품별 파일 뼈대 (scale, powder, pill, dispense, board.h), 28BYJ 직결 테스트
2026-10-16 하드웨어: KiCad 제어 기판 시안 (회로도, PCB 배치, 3D), DRV8833 모듈 핀 정정 (nFAULT 없음, STBY)
2026-10-16 HANDOFF: 펌웨어 뼈대와 부품 도착 후 순서
2026-10-16 담기 실패 보고 (POST /dispenses/{id}/fail, 화면 Failed), 펌웨어 Wi-Fi 끊기면 다시 연결
2026-10-27 가루 모터 PWM 속도 조절 (느린 감쇠), 쿠폰 · 부품 실측 반영, 만능기판 납땜 배치
    - 펌웨어: powder_init (핀 8개 + LEDC 20kHz), powder_set (방향 + 듀티 + 느린 감쇠), 28BYJ 직결 테스트 호출 막음, TODO 표시 정리
    - 3D: 쿠폰 J5 · M5 · H3 · 자석, JGA 지름 실측, 로드셀 구멍 위치(고정 끝 · 하중 끝 따로), 홀 센서 실측. check.py 통과
    - 만능기판: perfboard.py (배치 + 연결 검사 + 2D · 3D · 연결도), DRV8833 줄 간격 6칸 · 크기 21.3 × 18.4 실측
    - 부품: 수 핀헤더 · F-F 30cm 추가 주문, F-F 점퍼 길이 30cm 정정, 터미널 블록 안 씀
    - HANDOFF 상태 요약 갱신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
